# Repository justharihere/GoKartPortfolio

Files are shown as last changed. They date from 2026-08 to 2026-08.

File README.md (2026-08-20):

# GoKartPortfolio

A single-seat electric go-kart built from a salvaged e-bike drivetrain and a fully custom welded frame, now on its second build iteration (V2). Modeled end-to-end in CAD before fabrication, from initial concept through the load-bearing rear-wheel mount.

*Built summer 2026 · V2 rebuild logged March–May 2026 · 29 active build days across a 6-week window*

---

## CAD Model

**[→ Open the interactive CAD model (Autodesk Fusion, read-only)](https://gmail5378598.autodesk360.com/g/shares/SH28cd1QT2badd0ea72bc91f904d955a8b5e?mode=embed)**

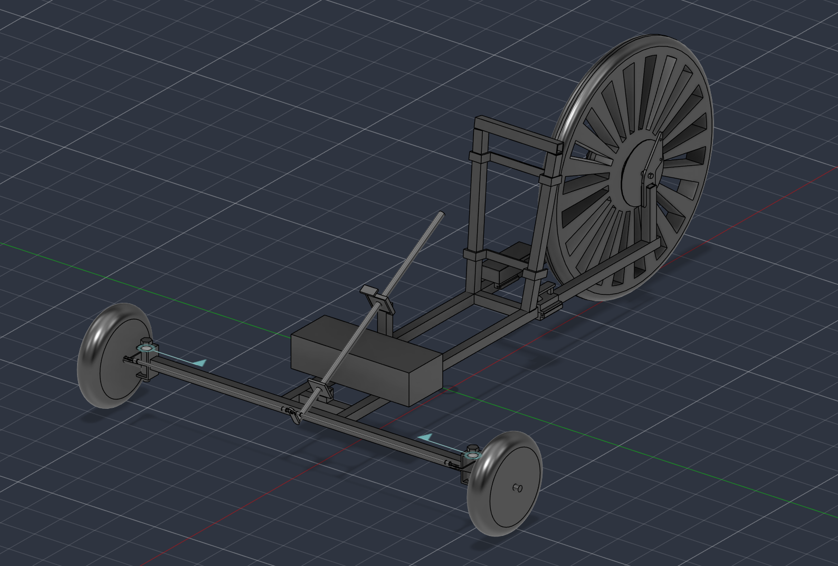
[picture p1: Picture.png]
CAD model screenshot


---

## Overview

- Salvaged the motor, battery, and controller from a decommissioned e-bike
- Modeled the full assembly in CAD before any fabrication began, using the model to plan geometry and sequence the build
- Designed a custom rear-wheel mount, sized against torque loading about the axle and iterated to reduce material cost and cutting waste
- Fabricated the frame from high-carbon steel using FCAW welding; cut stock to tolerance with an angle grinder
- Rebuilt the frame in a second iteration (V2), revising chassis and T-frame dimensions based on lessons from the first build

## Frame Dimensions (V2)

| Element | Measurement | Value |
|---|---|---|
| T-frame | Vertical | 122 cm |
| T-frame | Horizontal | 91.5 cm |
| Horizontal T-frame → chassis support bar 1 | Offset | 3.5 cm |
| Last chassis support bar → frame end | Offset | 48.2 cm |
| Wheel support | Height | 14 cm |
| Chassis bar 1 → chassis bar 2 | Spacing | 20.5 cm |

## Bill of Materials

| Part | Status | Qty | Cost | Location |
|---|---|---|---|---|
| New brackets (or old ones ground down) | Installed | 2 | — | Steering |
| 50×50mm 5/8" ID plates | Installed | 4 | — | Steering |
| 12" 5/8" OD hollow rod | Installed | 2 | — | Steering |
| 29.191mm rod, 30° cut from vertical, 1"×1" | Installed | 1 | — | Steering |
| 162.136mm rod, 30° cut from vertical, 1"×1" | Installed | 1 | — | Steering |
| 186.2mm, 1"×1" | Installed | 1 | — | Seat |
| 390mm rod, 10° cut from vertical, 1"×1" | Installed | 2 | — | Seat |
| 140.6mm, 1"×1" | Installed | 2 | — | Rear large wheel support |
| Left torque flat mount + brake | Installed | 1 | $26.88 | Rear large wheel support |
| Right torque flat mount | Installed | 1 | $22.87 | Rear large wheel support |
| 135.4mm, 1"×1" | Installed | 3 | — | Chassis |
| 915mm, 1"×1" | Installed | 1 | — | Chassis |
| 1220mm, 1"×1" | Installed | 2 | — | Chassis |

## Specs

| Spec | Value |
|---|---|
| Frame material | High-carbon steel |
| Welding process | FCAW |
| Drivetrain | Salvaged e-bike motor/battery/controller |
| Design tool | Autodesk Fusion |

## References

Standards and tolerance data used during design:

- [Shimano Disc Brake Standards (2019)](https://www.peterverdone.com/wp-content/uploads/2018/06/2019-Shimano-Disc-Brake-Standards.pdf)
- [Engineering working tolerances reference](https://www.an-engineering.co.uk/working-tolerances/)

## Media

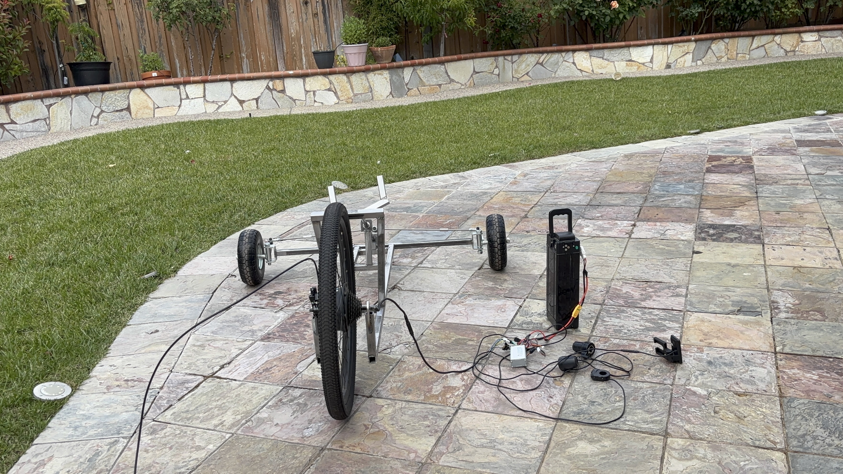
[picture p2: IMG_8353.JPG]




---

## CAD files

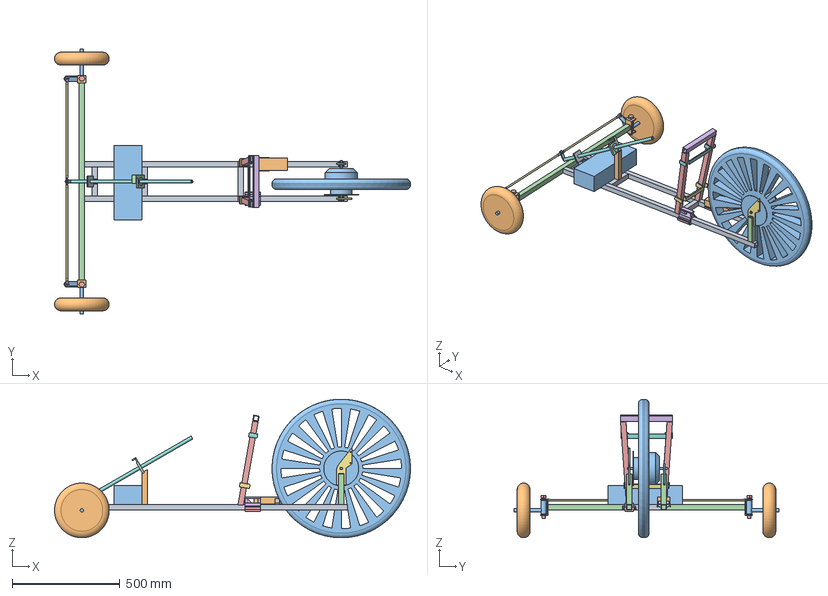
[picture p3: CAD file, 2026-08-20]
Chassis.step
1651.8 x 1229.4 x 642.6 mm

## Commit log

2026-08-20 Enhance README with project details and structure
    Expanded the README with detailed project information, including CAD model links, overview, build process, specifications, media sections, and suggested repo structure.
2026-08-20 Change CAD model screenshot to Picture.png
    Updated CAD model screenshot path in README.
2026-08-20 Revise README for V2 build details and specifications
    Updated README to reflect V2 build iteration, added detailed frame dimensions, bill of materials, and references.
